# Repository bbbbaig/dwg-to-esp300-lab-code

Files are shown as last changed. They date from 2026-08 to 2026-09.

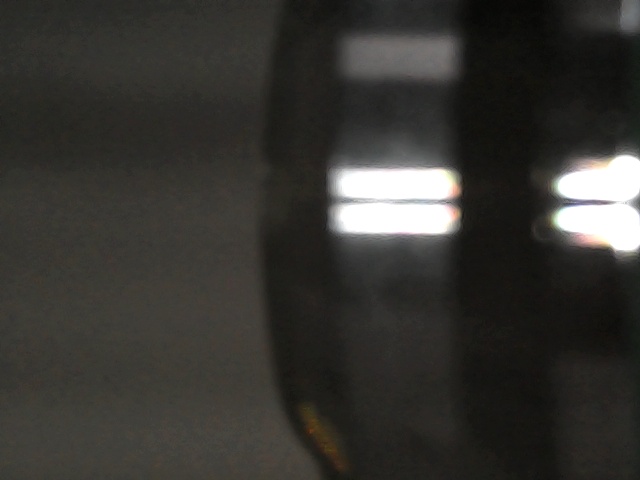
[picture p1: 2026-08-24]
camera_snapshot.jpg

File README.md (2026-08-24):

# DWG/DXF to ESP300 laser path

This project turns CAD geometry into an ESP300 stage-control Python script.
It follows the style of `ESP300_Controller.ipynb`: serial commands such as
`1PA...`, `2PA...`, `1VA...`, and `2VA...` are generated for the X/Y stage.

## Generate code from the sample DWG

The generated stage coordinates are always in millimeters. For the sample DWG,
the longest side is calibrated to 25 mm, which also makes the circular holes
about 2 mm in diameter.

```powershell
py dwg_to_esp300.py `
  "C:\Users\QCQN\Downloads\laser_shield\adjust25design.dwg" `
  --output adjust25design_esp300.py `
  --preview adjust25design_preview.svg `
  --fit-longest-mm 25 `
  --origin-x 0 `
  --origin-y 0 `
  --feed-rate 0.4 `
  --travel-rate 1.0 `
  --passes 1 `
  --ipynb
```

Generated files:

- `adjust25design_esp300.py`: executable ESP300 motion script
- `adjust25design_esp300.ipynb`: Jupyter notebook version when `--ipynb` is used
- `adjust25design_preview.svg`: path preview in machine millimeters
- `adjust25design.converted.dxf`: intermediate DXF when the input is DWG

Use `--notebook-output path\to\job.ipynb` if you want to choose the notebook
path explicitly.

## Run the generated machine script

Open and inspect the generated script first. The generated file now follows the
notebook style: `send()`, `move_abs()`, `move_rel()`, and `set_velocity()` are
top-level functions. Repeated cuts are stored as `PASSES = 5` when all selected
paths share the same count, or as per-path `passes` when they differ. The laser
hooks are intentionally no-ops unless you fill in laser trigger commands.
Default live speeds follow the field notebooks conservatively: `0.4 mm/s` for
cutting, `1.0 mm/s` for travel, and `0.3 mm/s` for Z motion.

```powershell
py adjust25design_esp300.py --dry-run
py adjust25design_esp300.py --live --port COM5
py adjust25design_esp300.py --live --port COM5 --passes 2
```

In Jupyter, open the generated `.ipynb`, run the setup cells, inspect
`METADATA`, and only set `LIVE_RUN = True` after checking the preview, COM port,
pass count, speed, and laser trigger commands.

## Visualize the generated movement

```powershell
py visualizer_server.py --host 127.0.0.1 --port 8765
```

Then open:

```text
http://127.0.0.1:8765
```

The visualizer reads the generated ESP300 scripts and animates the exact move
sequence. The full drawing view shows the 25.000 mm side; the outline view uses
only the `외형선(ISO)` layer.

The browser interface can now trace a new DWG/DXF directly:

- Choose a `.dwg` or `.dxf` file and press `Trace File`, or paste a local
  drawing path and press `Trace Path`.
- Use `직접 조합` to build paths without CAD. `빈 작업` starts an empty mm
  workspace, then add `직선`, `사각형`, or a fixed 2 mm `원`.
- `긴 변(mm)` sets the real-world size of the longest side. Use `25` for the
  current sample.
- Coordinates are generated in mm, and the circular-hole check is fixed at
  2 mm so it cannot be changed accidentally.
- Select paths from the canvas or the path list.
- Set pass counts per path, or use the global pass box and `Apply`.
- Keep `Optimize` enabled to reorder selected paths and repeated passes to
  reduce laser-off travel.
- Press `코드 다운로드` to write the selected plan under `generated/` and
  download the generated ESP300 Python file in the browser.

By default, generated path order is optimized to reduce laser-off travel moves.
Use `--no-optimize` only when you need to preserve the original CAD entity order.
By default, `--trace-mode design` excludes obvious watermark/support geometry
such as `layer 0` evaluation text and full-page diagonal strokes. Use
`--trace-mode all` only when you intentionally want every CAD entity.

## Notes

- DWG input is converted to DXF automatically with ODA File Converter when it is
  installed. If ODA is not found, the script tries `aspose-cad`.
- DXF input is parsed directly with `ezdxf`.
- The converter supports common curve geometry through `ezdxf.path.make_path`,
  including lines, polylines, arcs, circles, ellipses, and splines when `ezdxf`
  can flatten them.
- `--include-layer` and `--exclude-layer` accept shell-style wildcards.

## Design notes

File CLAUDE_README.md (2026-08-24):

# DWG to ESP300 Code Context

This repository/package is a local tool for converting DWG/DXF CAD geometry into
ESP300 stage-control Python code for laser engraving on a small glass sample.

The key physical assumption is that the laser beam is fixed and the glass/sample
stage moves in X, Y, and Z. During laser-off travel moves, the glass stage is
defocused in Z so the laser is not focused on the sample. During cutting moves,
the stage returns to the focus Z and the X/Y stage moves along the drawing path.
Default live speeds are set to conservative field-code values: cutting
`0.4 mm/s`, travel `1.0 mm/s`, Z motion `0.3 mm/s`, and serial command settle
`0.05 s`.

## Main Files

| File | Role |
| --- | --- |
| `dwg_to_esp300.py` | Command-line converter and ESP300 script generator. |
| `visualizer_server.py` | Local HTTP server/API for trace, plan, export, and download. |
| `visualizer/index.html` | Browser UI shell. |
| `visualizer/styles.css` | Browser UI styling. |
| `visualizer/app.js` | Frontend state, 2D canvas preview, and Three.js 3D visualization. |
| `visualizer/vendor/three.module.js` | Local Three.js dependency for the 3D view. |
| `adjust25design_2passes_esp300.py` | Example generated ESP300 script using two passes. |
| `adjust25design_2passes_esp300.ipynb` | Notebook form of the generated script. |
| `adjust25design_2passes_preview.svg` | Preview of the generated two-pass path. |
| `launch_dwg_to_esp300.ps1` | Windows launcher for the local app. |
| `requirements.txt` | Python dependencies. |
| `DWG_to_ESP300_Code_Overview_Lab_Report.pptx` | Plain lab-report slide deck explaining the code. |

## Conversion Pipeline

1. `dwg_to_esp300.py` accepts DWG or DXF input.
2. DWG input is converted to DXF when needed.
3. `ezdxf` extracts drawable geometry and flattens curves into point sequences.
4. The code filters likely annotation/helper geometry in design trace mode.
5. Geometry is scaled to millimeters and centered on the glass.
6. Scaling is capped so the path fits inside the centered 25 mm usable circle.
7. Optional path ordering optimization reduces non-cutting travel distance.
8. The generator writes an ESP300 Python script, optional notebook, and SVG preview.

## Motion Planning Logic

The server-side visualizer builds motion segments from selected paths:

- `z-defocus`: move glass Z away from focus before laser-off travel.
- `travel`: move X/Y with laser off and Z defocused.
- `z-focus`: return glass Z to focus before cutting.
- `cut`: move X/Y with laser on at focus Z.

The generated ESP300 script follows the same logic.

## Multi-Pass Logic

Each path can have its own pass count.

- Open paths alternate direction on repeated passes: forward, backward, forward,
  and so on.
- Closed paths repeat from an equivalent closed-loop start.
- The optimizer considers the expected endpoint after the requested pass count.

The optimizer is a heuristic, not a mathematical proof of the global shortest
route. It uses nearest-neighbor ordering and limited local search to reduce
travel.

## ESP300 Command Pattern

The generated script uses basic ESP300-style serial commands:

- `MO`: motor on
- `VA`: set axis velocity
- `PA`: absolute position move
- `TP`: read current position

X/Y synchronization is implemented by calculating a common move time for each
line segment:

```text
move_time = vector_distance / command_speed
vx = abs(dx) / move_time
vy = abs(dy) / move_time
```

Each axis receives its own velocity so both axes reach the endpoint together.

## Robustness Details

- `TP_READ_RETRIES = 5`
- Empty or unparseable `TP` replies are retried rather than treated as zero.
- Position wait loops tolerate intermittent TP failures.
- Extra settle time is applied after laser-off travel and Z focus/defocus moves.
- Z travel duration is computed from Z distance and configured Z speed.

## UI / Visualizer Details

The browser app provides:

- 2D drawing preview with the centered usable circle.
- 3D visualization showing the glass plate moving under a fixed laser tip.
- Path selection and per-path pass controls.
- Feed speed, travel speed, and Z speed controls.
- Export button that writes a generated ESP300 script into `generated/`.

The current UI uses side-by-side 2D and 3D panels on desktop. On small screens,
the panels stack vertically.

## Safety Notes

Before live use, confirm:

- The COM port and baudrate match the ESP300.
- Mechanical zero corresponds to the assumed glass center.
- The usable area matches the mounted sample and tape placement.
- The generated path stays inside the 25 mm circular usable area.
- Laser control is manual unless `LASER_ON_CMD` and `LASER_OFF_CMD` are filled
  with the correct device commands.

## Suggested Review Starting Points

1. Read `dwg_to_esp300.py` around `generate_esp300_script()`.
2. Read the generated `adjust25design_2passes_esp300.py` around `run_paths()`.
3. Read `visualizer_server.py` around `build_segments()`, `expand_passes()`, and
   `optimize_items()`.
4. Read `visualizer/app.js` around `updatePlan()`, `rebuildStage3d()`, and
   `updateStage3d()`.

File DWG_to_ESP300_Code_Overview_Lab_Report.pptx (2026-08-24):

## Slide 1

DWG to ESP300 코드 개요

연구실 보고서 형식

- 목적: CAD 도면을 ESP300 X/Y/Z 스테이지 구동 코드로 변환한다.
- 대상 장비: 25 mm x 25 mm 유리판이 움직이는 샘플 스테이지, 고정된 레이저 조사부.
- 주요 산출물: Python 실행 코드, Jupyter notebook, SVG preview, 브라우저 2D/3D visualizer.
- 본 슬라이드는 코드 구조와 실험 전 확인해야 할 동기화/초점 로직을 요약한다.

DWG to ESP300 code overview | 1/11

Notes: [Sources]
- README.md
- dwg_to_esp300.py
- visualizer_server.py
- visualizer/app.js

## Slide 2

실험 장치 전제를 코드에 고정했다

- 유리판 크기는 25 mm x 25 mm로 취급한다.
- 사용 가능 영역은 중앙 원형 영역이며, 기본 지름은 25 mm이다.
- 좌표 시작점은 유리판 중심, 즉 (12.5 mm, 12.5 mm)이다.
- 레이저는 고정되어 있고 실제 이동 대상은 유리판/스테이지이다.
- 기본 laser_on()/laser_off()는 출력문이며, TTL 제어 명령은 별도 입력 가능하다.

DWG to ESP300 code overview | 2/11

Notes: [Sources]
- dwg_to_esp300.py lines 1311-1368
- visualizer_server.py lines 135-145
- visualizer/app.js lines 622-650

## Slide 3

파일 구성은 변환, 서버, UI, 산출물로 나뉜다

Core files

- dwg_to_esp300.py: DWG/DXF geometry를 읽고 ESP300 Python script와 notebook을 생성한다.
- visualizer_server.py: local HTTP API로 trace, plan, export, download를 처리한다.
- visualizer/app.js: 2D preview와 3D 유리판 이동 시뮬레이션을 렌더링한다.

Run and outputs

- generated/: UI에서 export한 선택 경로별 ESP300 코드가 저장된다.
- launch_dwg_to_esp300.ps1: 바탕화면 바로가기에서 서버와 UI를 열기 위한 launcher이다.

DWG to ESP300 code overview | 3/11

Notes: [Sources]
- README.md
- REVIEW_PACKAGE_README.txt
- visualizer_server.py lines 739-895

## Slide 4

DWG/DXF 변환 파이프라인

- 1. DWG 입력은 DXF로 변환하거나, DXF 입력은 그대로 사용한다.
- 2. ezdxf로 LINE, POLYLINE, ARC, SPLINE 등 geometry를 점열로 flatten한다.
- 3. design trace mode에서는 주석/전역 보조선으로 보이는 path를 걸러낸다.
- 4. 단위는 mm 기준으로 변환하고, 도면을 유리판 중심에 맞춘다.
- 5. 최종 scale은 중앙 사용 가능 원 안에 들어가도록 한 번 더 제한한다.

DWG to ESP300 code overview | 4/11

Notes: [Sources]
- dwg_to_esp300.py lines 205-318
- dwg_to_esp300.py lines 324-406
- dwg_to_esp300.py lines 1317-1336

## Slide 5

경로 순서는 이동 거리 감소를 목표로 최적화한다

- 초기 순서는 현재 위치에서 가장 가까운 path를 고르는 greedy 방식이다.
- 열린 path는 시작점과 끝점 중 현재 위치에 가까운 방향으로 뒤집을 수 있다.
- 닫힌 path는 현재 위치와 가장 가까운 점을 시작점으로 회전한다.
- 이후 제한적인 local search로 순서를 개선한다.
- 따라서 전역 최단 경로 보장은 아니지만, 실험용 travel 감소 heuristic으로 동작한다.

DWG to ESP300 code overview | 5/11

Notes: [Sources]
- dwg_to_esp300.py lines 421-550
- visualizer_server.py lines 407-473

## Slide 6

passes가 2 이상일 때 이동 끝점을 고려한다

- 각 path의 pass count는 UI 또는 실행 인자로 지정된다.
- 열린 path는 pass마다 forward/backward를 번갈아 사용해 불필요한 되돌아가기를 줄인다.
- 닫힌 path는 같은 폐곡선 방향을 반복해도 끝점이 시작점과 같으므로 안정적이다.
- visualizer_server.py는 pass 이후 예상 endpoint를 계산해 다음 path 순서 최적화에 반영한다.
- 생성된 script도 같은 alternating-pass 규칙으로 실제 move를 실행한다.

DWG to ESP300 code overview | 6/11

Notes: [Sources]
- visualizer_server.py lines 368-418
- dwg_to_esp300.py lines 851-856
- dwg_to_esp300.py lines 979-996

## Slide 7

ESP300 명령은 축별 absolute move와 position wait로 구성된다

- 축 번호는 X=1, Y=2, Z=3으로 정의된다.
- 기본 명령 패턴은 MO, VA, PA, TP이다.
- move_abs()는 PA 명령, set_velocity()는 VA 명령을 보낸다.
- get_position()은 TP 응답을 읽고 빈 응답 또는 파싱 실패 시 5회 재시도한다.
- wait_xy_position()과 wait_axis_position()은 목표 좌표 도달 여부를 position tolerance로 확인한다.

DWG to ESP300 code overview | 7/11

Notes: [Sources]
- dwg_to_esp300.py lines 610-632
- dwg_to_esp300.py lines 733-818

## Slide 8

X/Y 동기화는 같은 도착 시간을 만들도록 계산한다

- 직선 segment의 전체 이동 시간은 vector distance / command speed로 계산한다.
- X축 속도는 abs(dx) / move_time, Y축 속도는 abs(dy) / move_time로 설정한다.
- 두 축의 PA 명령은 거의 연속으로 전송되어 같은 시간에 목표점에 도달하도록 한다.
- position wait mode에서는 TP 기반으로 실제 도달을 확인한다.
- Y축 관련 짧은 멈춤/드리프트 완화를 위해 travel 이후 추가 settle time을 둔다.

DWG to ESP300 code overview | 8/11

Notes: [Sources]
- dwg_to_esp300.py lines 925-959
- dwg_to_esp300.py lines 624-627

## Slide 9

Laser-off travel에서는 유리판 Z를 defocus한다

- 다음 cut 시작점까지 XY travel이 필요할 때만 laser off와 Z defocus를 수행한다.
- 기본 defocus는 focus_z에서 1 mm 이동하며, 이동 시간은 Z speed로 계산된다.
- Z 이동 후에는 position wait 또는 sleep wait를 적용하고 settle time을 둔다.
- 연속된 cut 구간 또는 같은 위치에서 다시 자르는 경우에는 굳이 Z를 바꾸지 않는다.
- 마지막 종료 단계에서도 laser off 후 defocus 위치로 이동해 안전 상태로 마무리한다.

DWG to ESP300 code overview | 9/11

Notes: [Sources]
- visualizer_server.py lines 231-327
- dwg_to_esp300.py lines 859-923
- dwg_to_esp300.py lines 963-976
- dwg_to_esp300.py lines 1021-1034

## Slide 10

Visualizer는 계획과 실제 코드 생성을 연결한다

- 2D panel은 도면 경로, 중앙 사용 가능 원, 진행된 cut/travel segment를 표시한다.
- 3D panel은 고정 레이저 아래에서 유리판과 도면이 X/Y/Z로 움직이는 모습을 보여준다.
- 사용자는 path 선택, pass count, feed/travel/Z speed, optimize 여부를 조정할 수 있다.
- /api/plan은 선택된 경로를 motion segment로 만들고, /api/export는 ESP300 script를 생성한다.
- 현재 UI는 2D와 3D를 좌우 배치하여 공간 활용과 가시성을 개선했다.

DWG to ESP300 code overview | 10/11

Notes: [Sources]
- visualizer/app.js lines 109-120
- visualizer/app.js lines 321-370
- visualizer/app.js lines 488-930
- visualizer_server.py lines 778-895

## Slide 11

검증 상태와 실제 실행 전 확인 사항

- Python compile check와 JavaScript parser check를 통과했다.
- 생성된 2-pass path는 25 mm 중앙 원 안에 margin 0.05 mm 조건으로 배치된다.
- TP read retry, empty TP handling, travel/Z settle time 보강이 반영되어 있다.
- Live run 전에는 dry-run 출력, visualizer path, mechanical zero, sample mounting을 확인해야 한다.
- 남은 한계: 최적화는 heuristic이며, 실제 레이저 TTL 제어는 장비 연결 방식에 맞춰 별도 검증이 필요하다.

DWG to ESP300 code overview | 11/11

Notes: [Sources]
- REVIEW_PACKAGE_README.txt
- dwg_to_esp300.py
- visualizer_server.py
- visualizer/app.js

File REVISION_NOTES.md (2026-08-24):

# DWG to ESP300 Lab Code Package — 개정 내역

개정일: 2026-08-17
대상 패키지: DWG_to_ESP300_Lab_Code_Package_2026-08-16
변경 파일: `visualizer_server.py`, `dwg_to_esp300.py`, `visualizer/index.html`, `visualizer/app.js`, `visualizer/styles.css`

## 1. 개요

기존 패키지는 DWG/DXF 도면을 ESP300 스테이지 제어 코드로 변환하고 미리보기하는 기능까지 제공하였다. 본 개정에서는 브라우저 인터페이스에서 ESP300을 직접 수동 조작(조그, joystick jog)할 수 있는 기능을 추가하고, 시리얼 통신 안정성 및 다중 패스 가공 관련 사항을 보완하였다.

## 2. 신규 기능

### 2.1 수동 조그(Joystick) 제어 패널

시각화 인터페이스(`visualizer/`)에 실기계 수동 이동 제어 패널을 신설하였다. 백엔드는 `visualizer_server.py`의 `JogController` 클래스가 담당하며, ESP300과의 시리얼 통신은 기존 생성 스크립트와 동일한 명령 체계(VA, PA, MO, MF, TP, AB)를 사용한다.

| 기능 | 설명 |
|---|---|
| 연결(Connect) | COM 포트, 통신 속도, X/Y 및 Z 소프트 리밋 범위 지정. Dry run(가상 실행) 모드 기본 적용 |
| 축별 조그 이동 | X, Y, Z 축 개별 이동. 이동 단위 0.001mm(1μm)~5mm 중 선택 가능. 버튼 길게 누름으로 연속 이동, 포인터 해제 시 즉시 정지 |
| 키보드 단축키 | 방향키(X/Y), Page Up/Down(Z), Space(비상정지) |
| 비상정지(E-STOP) | 전축 정지 및 모터 비활성화 명령 전송, 진행 중인 자동 실행도 함께 중단. 재사용 시 재연결 필요 |
| 원점 이동(Home) | 소프트웨어 기준 원점(0,0,0)으로 절대 이동 |
| 로컬 원점 설정 | 현재 위치를 임의 좌표(통상 도면 중심)로 라벨링. **ESP300 자체의 절대 좌표계는 변경하지 않으며, 물리적 이동도 발생하지 않는다.** 소프트웨어 계층에서만 좌표 오프셋을 관리한다 |
| 좌표 직접 이동(Go to) | X/Y/Z 좌표 직접 입력 후 절대 이동, 소프트 리밋 적용 |
| 계획 경로 실행(Run on machine) | 화면에 표시된 가공 계획(경로 계획)을 실기계가 순차 실행. 실행 진행 상황에 따라 화면 재생 위치가 동기화된다 |
| 실시간 위치 표시 | 조그 조작 또는 외부 조작으로 발생한 실제 스테이지 이동이 3차원 미리보기 및 좌표 표시에 실시간 반영된다 |

안전 관련 사항: X/Y 이동은 원형 작업영역 반경으로, Z 이동은 지정 범위로 제한된다. 단일 조그 이동 최대 거리는 5mm로 고정되어 있다. 원점 이동, 좌표 직접 이동 등 상대적으로 큰 이동을 수반하는 동작은 실행 전 확인 절차를 거친다.

### 2.2 다중 패스 가공 시 Z축 보정

동일 경로를 다중 패스(pass)로 반복 가공할 경우, 2패스마다 초점(focus) Z 위치를 디포커스 방향으로 1μm(0.001mm)씩 후퇴시키는 로직을 추가하였다. 이는 반복 가공에 따른 가공면 침하를 보정하기 위한 것이다. 경로가 전환되면 해당 보정값은 자동으로 초기화된다.

적용 범위: 생성되는 독립 실행 스크립트(`dwg_to_esp300.py`의 `generate_esp300_script` 출력) 및 시각화 인터페이스의 경로 계획·실기계 실행 기능(`visualizer_server.py`) 양쪽 모두.

### 2.3 도면 배치 회전(45도)

원형 작업영역(지름 25mm)에 도면을 맞춰 넣을 때, 도면을 자체 중심 기준 45도 회전한 뒤 배율을 계산하도록 변경하였다. 정사각형이 아닌 배치의 경우, 회전 적용 시 축 정렬 배치 대비 더 큰 배율로 작업영역에 수용할 수 있다. 기본값은 45도이며, 0으로 설정 시 비활성화된다.

적용 범위: CLI 옵션(`--rotate-deg`, `dwg_to_esp300.py`) 및 브라우저 인터페이스(툴바 "Rotate (deg)" 입력란).

## 3. 결함 수정

### 3.1 시리얼 응답 처리 오류

위치 조회(TP) 명령에 대한 응답을 수신 완료로 판단하는 기준이 불명확하여, 응답이 통신 구간에서 분할 수신되는 경우 이전 응답의 잔여 바이트가 다음 응답에 혼입되는 결함이 있었다. 이로 인해 실제 위치값이 정상 범위를 크게 벗어난 값(예: 400mm 이상)으로 오표시되는 현상이 발생하였다.

조치: 응답 종결 문자(캐리지리턴/개행)를 확인한 후 응답 완료로 판단하도록 변경하였으며, 파싱된 값이 축 이동 범위를 초과하는 경우(250mm 초과) 해당 값을 폐기하고 재조회하도록 방어 로직을 추가하였다.

### 3.2 원점 이동 기능 오동작

`JogController` 클래스 내부에서 속성명과 메서드명이 중복되어(`home`) 원점 이동 기능 호출 시 오류가 발생하던 결함을 수정하였다.

### 3.3 인터페이스 레이아웃 오류

조그 패널 추가로 인해 우측 패널의 그리드 레이아웃 정의가 실제 구성요소 수와 불일치하여 하위 요소(도형 편집, 경로 목록)가 정상적으로 선택되지 않던 문제를 수정하였다.

## 4. 참고 및 제한사항

- **Python 버전 호환성**: `visualizer_server.py`는 `cgi` 모듈을 사용하며, 이는 Python 3.13부터 표준 라이브러리에서 제거되었다. Python 3.12 이하 환경에서 실행할 것을 권장한다.
- **전원 관리**: 실행 환경(PC)이 절전 모드로 전환되는 경우 USB 시리얼 연결이 끊기거나 포트 번호가 변경될 수 있다. 조그 조작 또는 자동 실행 중에는 운영체제 절전 설정을 비활성화할 것을 권장한다.
- DWG 파일 변환을 위하여 `aspose-cad` 패키지를 추가 설치하였다(ODA File Converter 미설치 환경 대응).

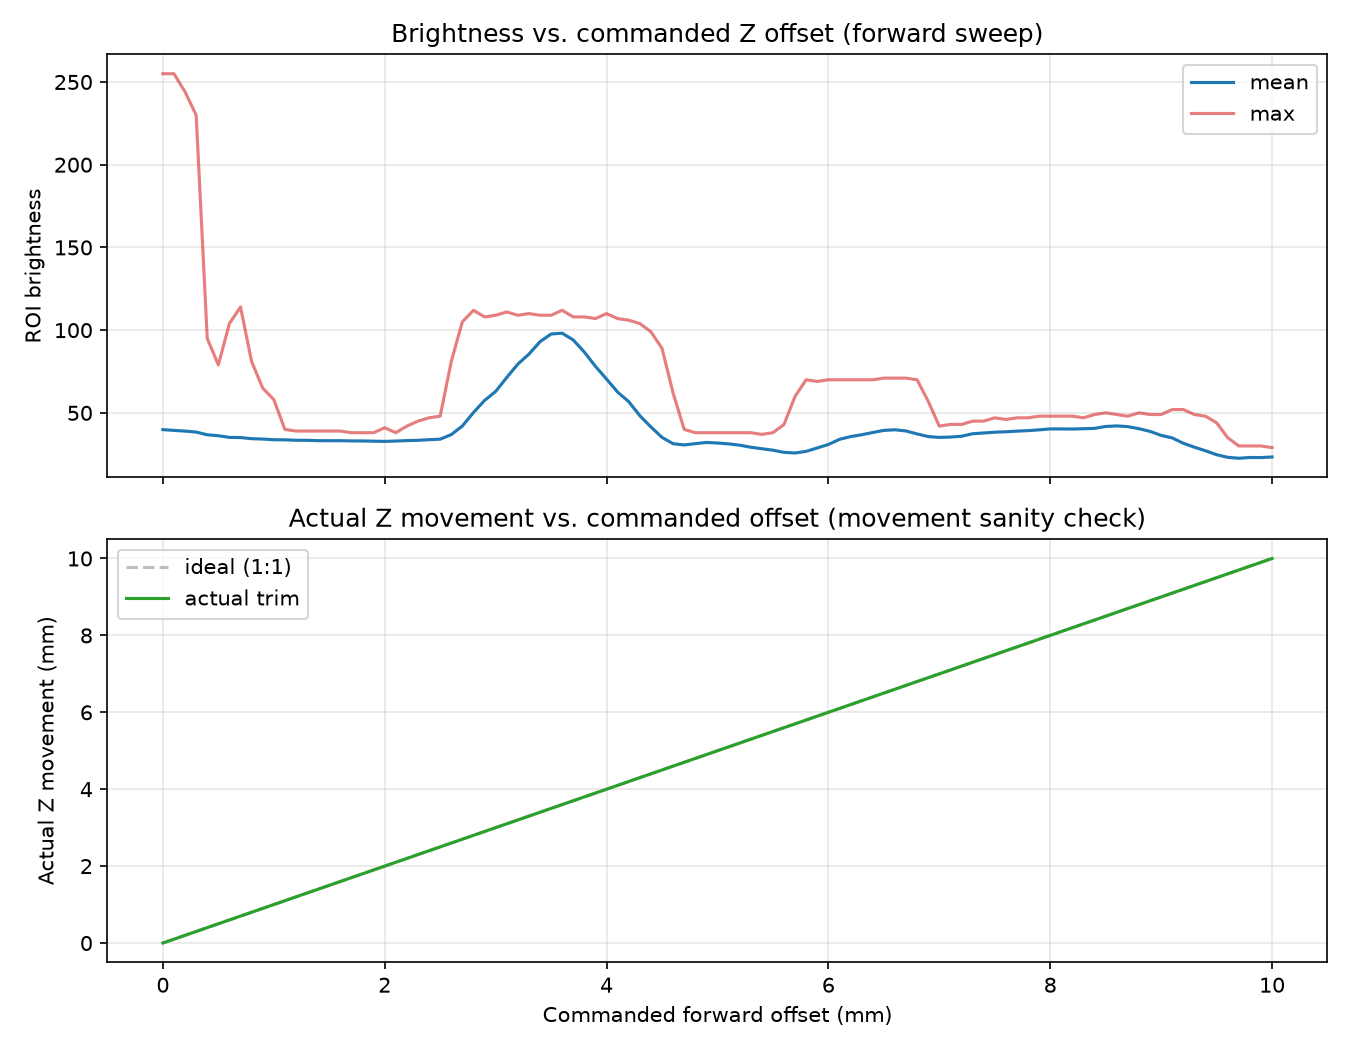
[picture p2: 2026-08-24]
zaxis_diagnostic.png

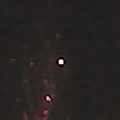
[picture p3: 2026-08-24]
camera_hotspot_check.jpg

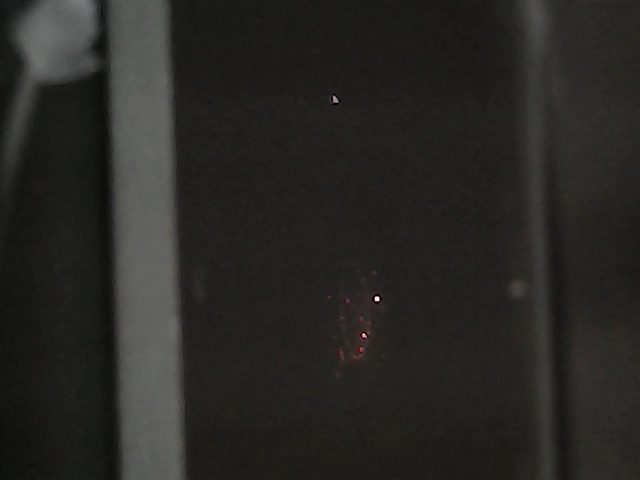
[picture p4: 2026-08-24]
camera_snapshot3.jpg

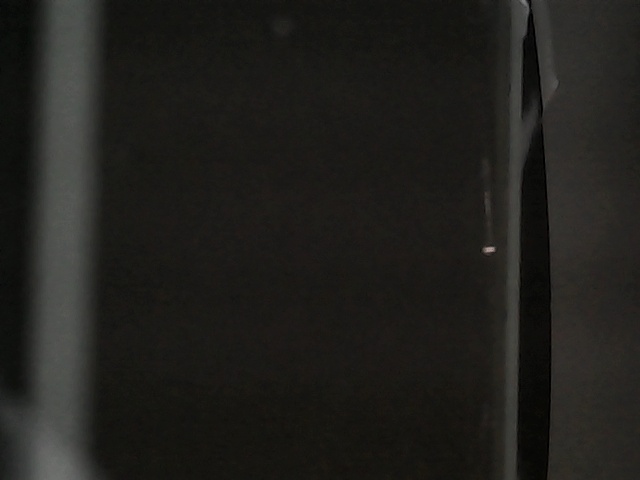
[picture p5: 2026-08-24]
camera_snapshot2.jpg

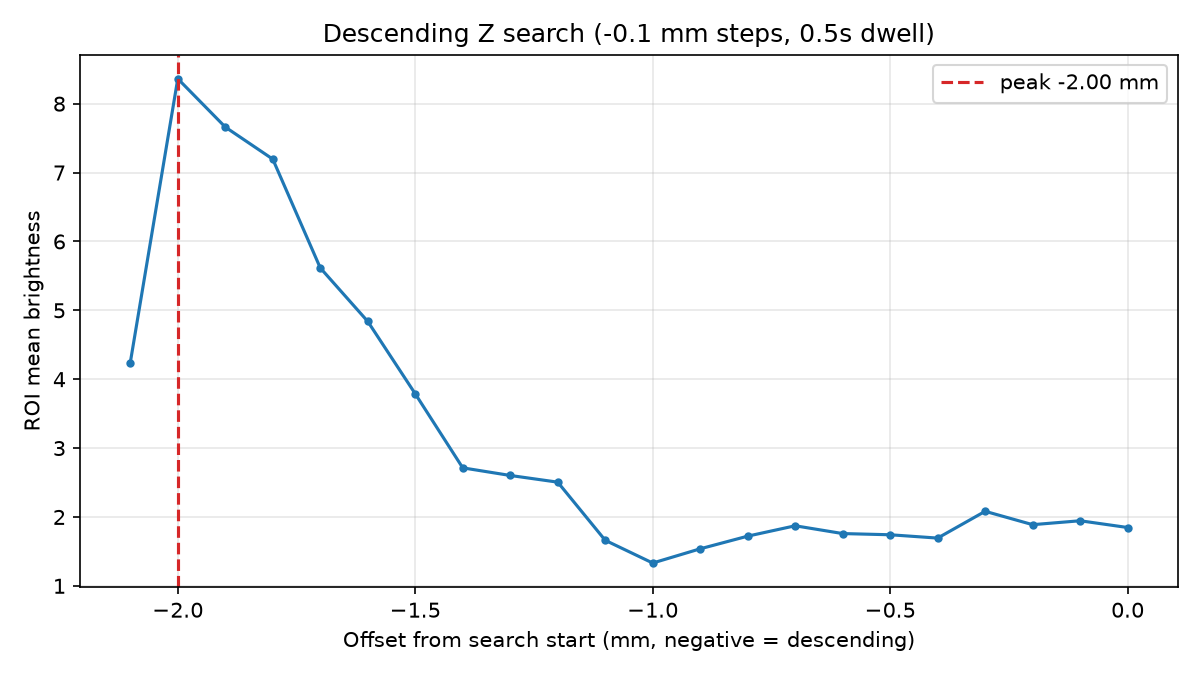
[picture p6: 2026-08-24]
descending_search.png

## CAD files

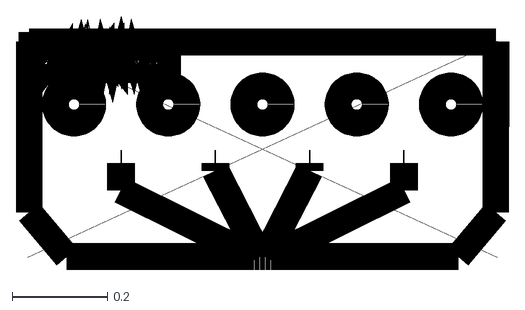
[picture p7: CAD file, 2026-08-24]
generated/adjust25design_ee601a7d4dee_esp300.converted.dxf
1.03 x 0.532

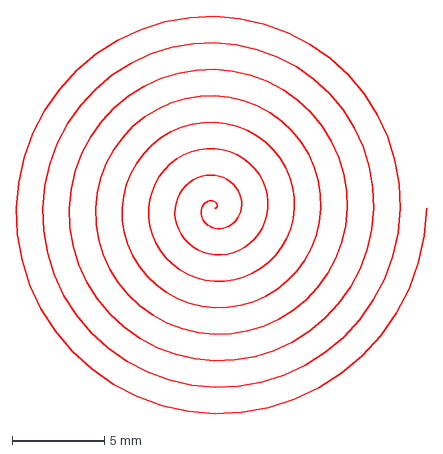
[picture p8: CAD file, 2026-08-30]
spiral_survey.dxf
22.3 x 21.6 mm

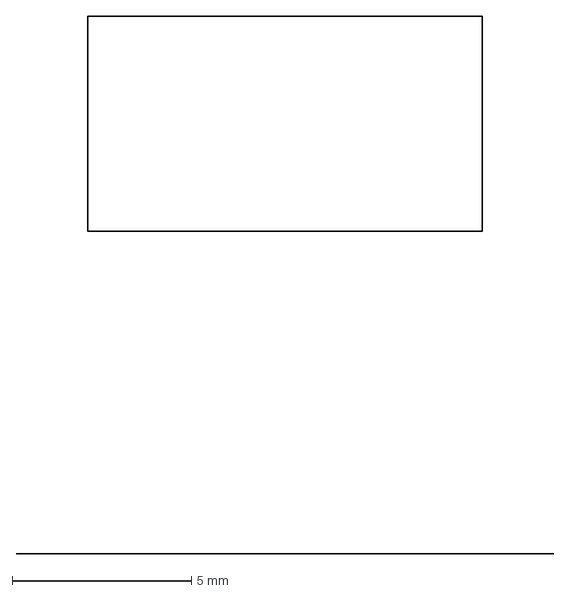
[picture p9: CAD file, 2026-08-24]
focus_test_line_rect.dxf
15.0 x 15.0 mm

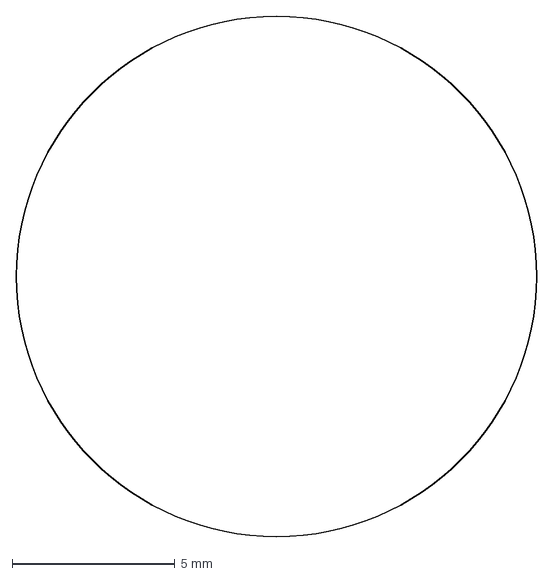
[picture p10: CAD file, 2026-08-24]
focus_test_circle.dxf
16.0 x 16.0 mm

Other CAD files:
focus_test_line.dxf
focus_test_2mm_line_x.dxf

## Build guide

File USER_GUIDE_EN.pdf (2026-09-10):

### DWG to ESP300

USER GUIDE

# From one drawing to a moving laser

DWG to ESP300 turns a drawing into laser stage motion,

### focuses the beam automatically with a camera, and lets you

watch the real machine as it runs — all from one screen. This guide takes you through every step, start to finish.

DWG to ESP300 · User Guide | 2026-09-10

DWG to ESP300 | User Guide

GETTING STARTED

# What does this app do?

It loads a drawing, lets you preview it, and runs the real machine — all in one window.

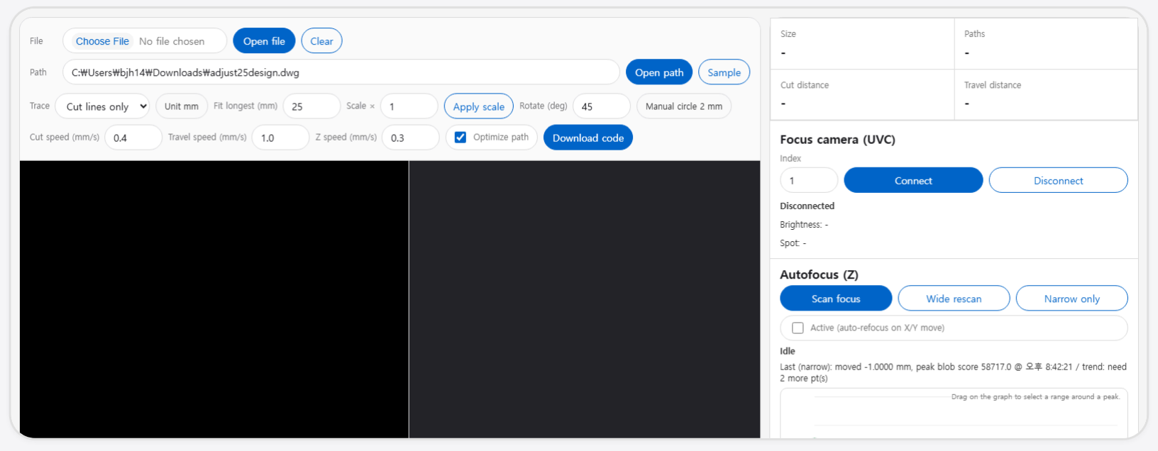
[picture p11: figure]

### 1 Load a drawing

Start by opening a drawing file (DWG or DXF) you already have.

### 2 Preview it on screen

See exactly how it will move, in both 2D and 3D, before anything happens.

### 3 Let the camera focus it

The connected camera finds the sharpest position on its own.

### 4 Run it on the real machine

Once you're happy with the preview, run the same plan for real.

DWG to ESP300 User Guide | 2

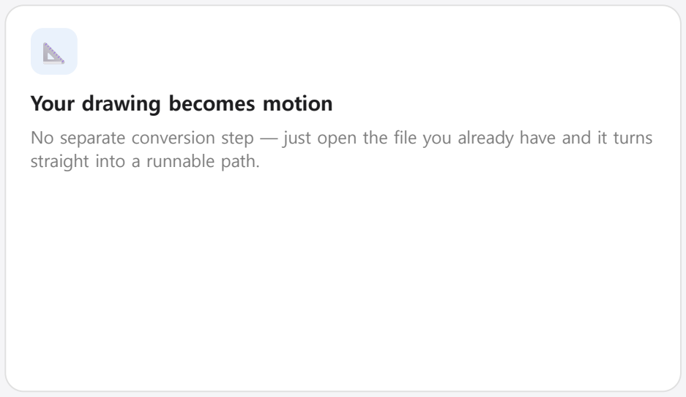
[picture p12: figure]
Your drawing becomes motion; straight into a runnable path.
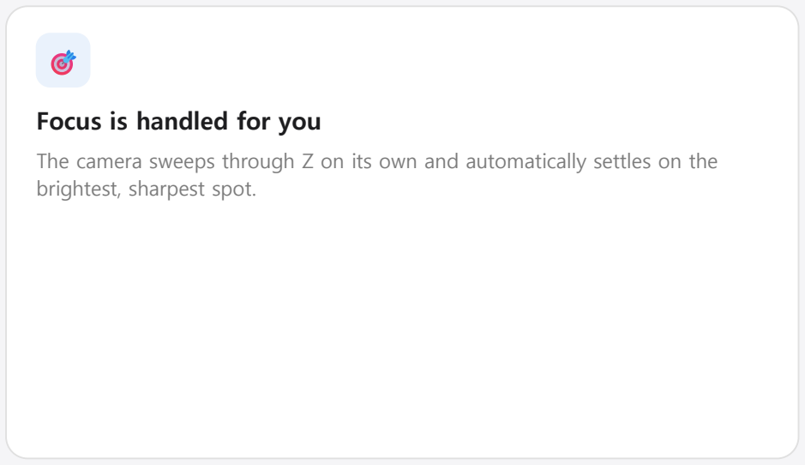
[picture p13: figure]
Focus is handled for you; brightest, sharpest spot.

GETTING STARTED

# Key features

Four things that make this app worth using.

No separate conversion step — just open the file you already have and it turns

The camera sweeps through Z on its own and automatically settles on the

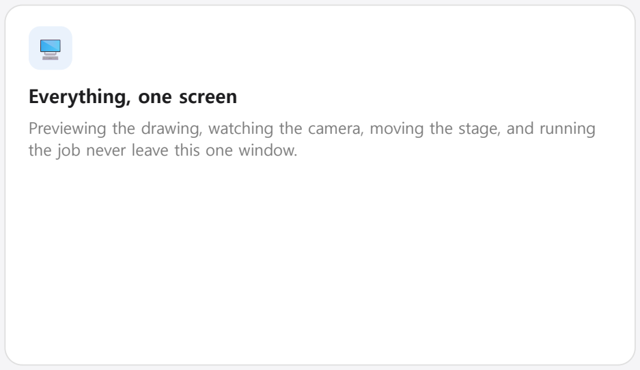
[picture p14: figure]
Everything, one screen; the job never leave this one window.

Previewing the drawing, watching the camera, moving the stage, and running

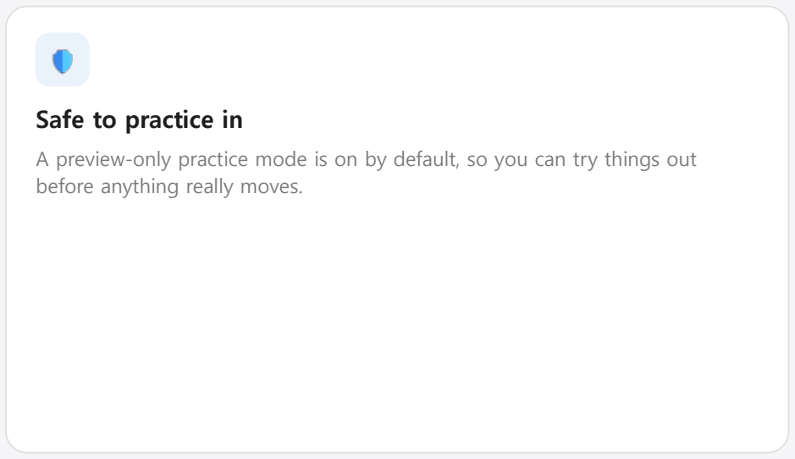
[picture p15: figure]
Safe to practice in; before anything really moves.

A preview-only practice mode is on by default, so you can try things out

FIRST LAUNCH · STEP 01

# Before you start

One icon on the desktop is all it takes to launch the app.

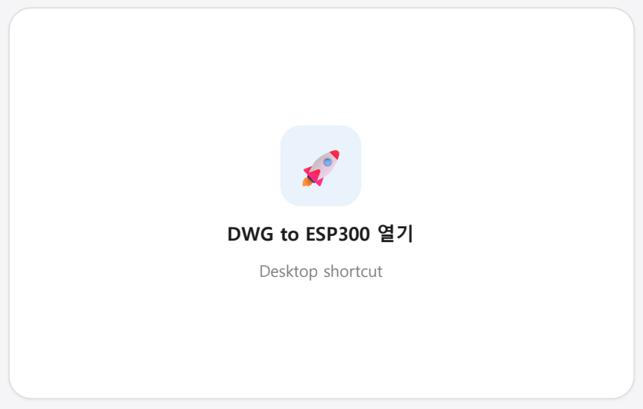
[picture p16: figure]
DWG to ESP300 열기; Desktop shortcut

### 1 Double-click "DWG to ESP300 열기" on the desktop

The app starts, and a browser window opens on its own a moment later.

### 2 Give it a few seconds

The very first launch can take a little longer than usual.

### 3 Already running? No need to relaunch

Clicking the icon again just brings you back to the window that's already open.

Good to know. If the computer goes to sleep, the connection to the machine can drop. Turn off sleep mode while you're working.

MAIN SCREEN · STEP 02

# The main screen at a glance

The screen splits into two halves: your workspace on the left, the tool panel on the

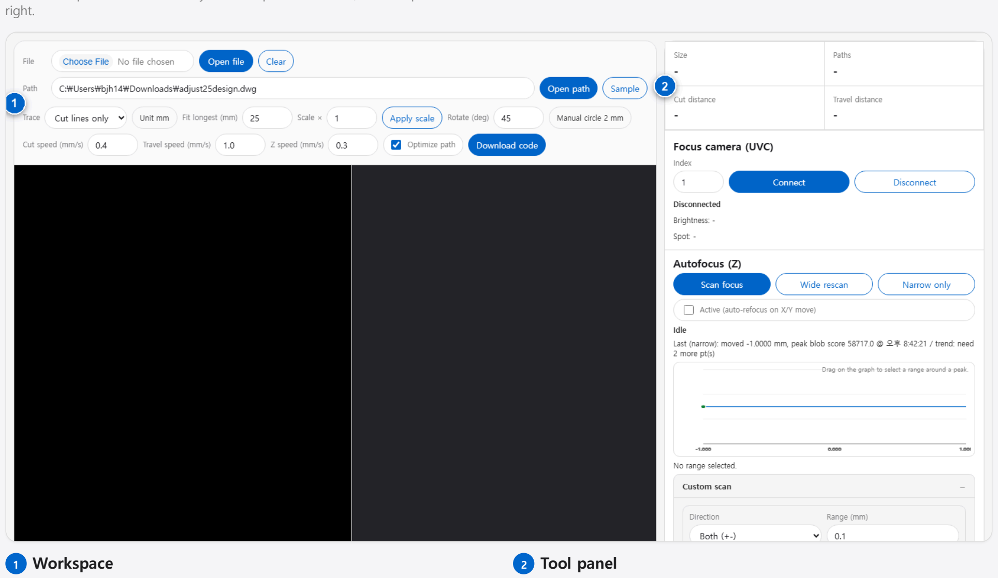
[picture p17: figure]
right.; 1 Workspace; 2 Tool panel

Where you open a drawing, check it, and play it back.

The camera view, focus controls, and machine controls all live here.

# Load a drawing

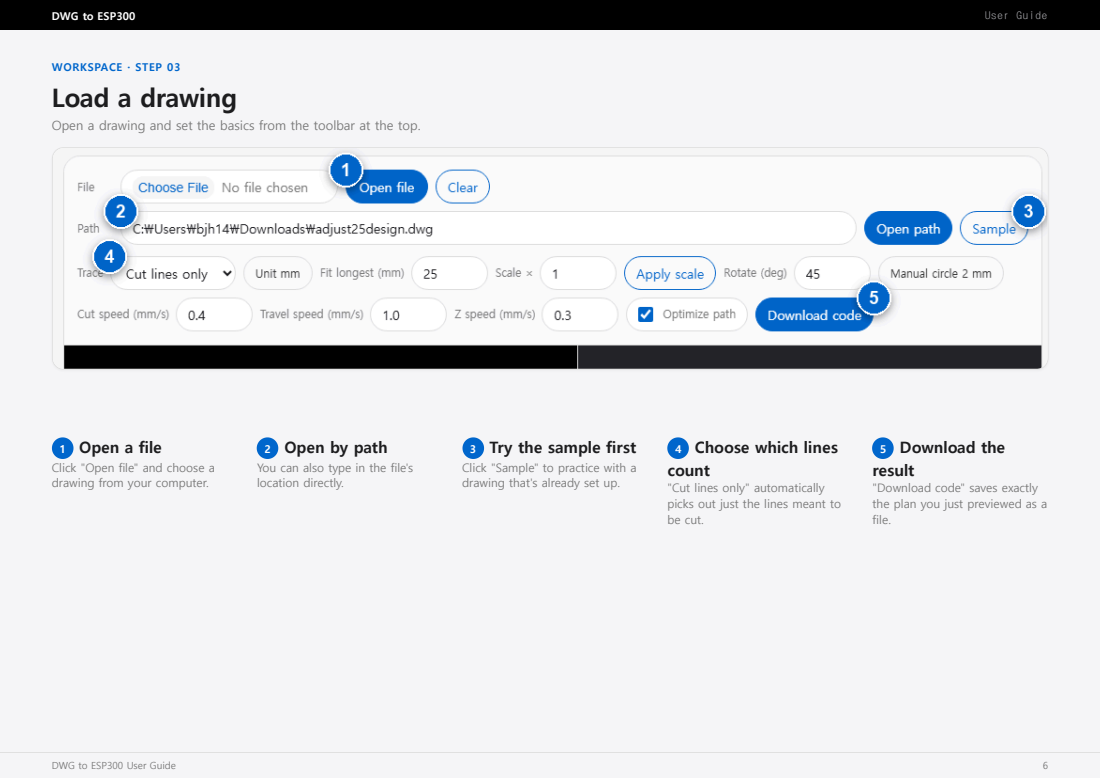
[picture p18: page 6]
WORKSPACE · STEP 03

Open a drawing and set the basics from the toolbar at the top.

1 Open a file
Click "Open file" and choose a
drawing from your computer.

2 Open by path
You can also type in the file's
location directly.

3 Try the sample first
Click "Sample" to practice with a
drawing that's already set up.

4 Choose which lines
count
"Cut lines only" automatically
picks out just the lines meant to
be cut.

5 Download the
result
"Download code" saves exactly
the plan you just previewed as a
file.

WORKSPACE · STEP 04

# Check it in the preview

Before anything runs for real, see how it will move right on screen.

### 1 Play the motion back

Press ▶ to play the path in real order. Drag the bar underneath to jump straight to any point.

The left side is a top-down 2D view; the right side looks like the real machine in 3D. Drag with your mouse on the 3D view to rotate it to any angle.

Good to know. The bar at the bottom shows the laser on/off state, the current height, and progress, all updating live.

# Watch the camera live

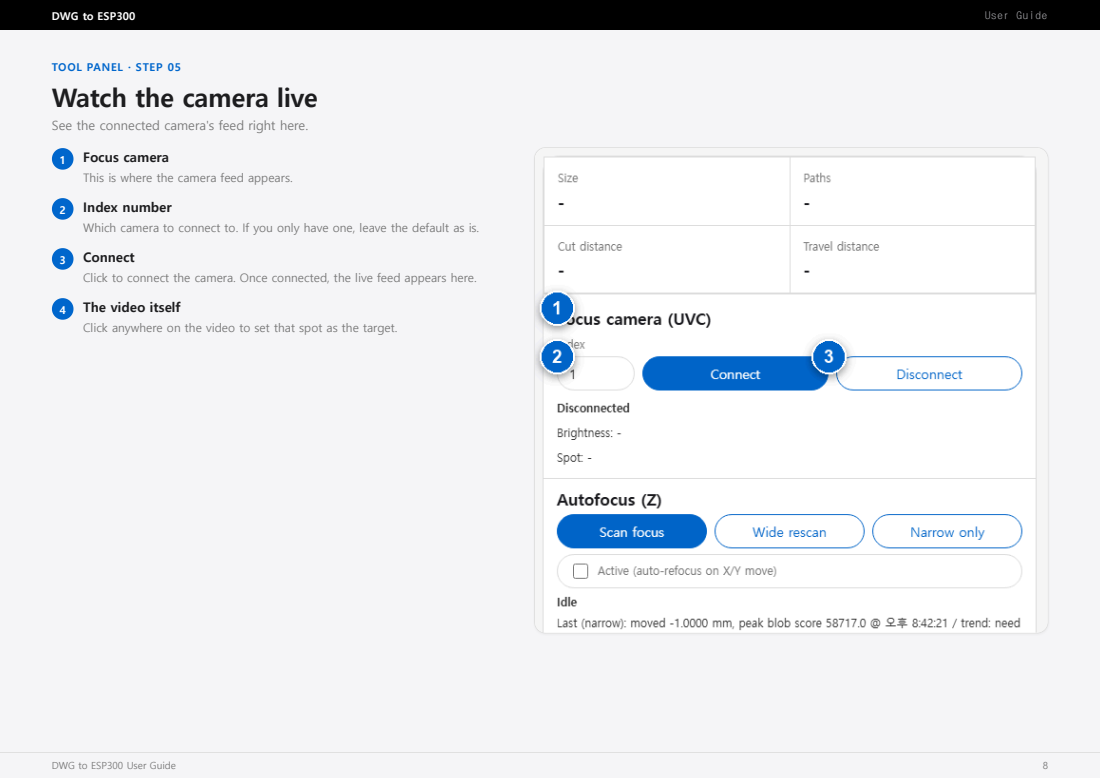
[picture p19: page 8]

TOOL PANEL · STEP 05

See the connected camera's feed right here.

1 Focus camera
This is where the camera feed appears.
2 Index number
Which camera to connect to. If you only have one, leave the default as is.
3 Connect
Click to connect the camera. Once connected, the live feed appears here.
4 The video itself
Click anywhere on the video to set that spot as the target.

TOOL PANEL · STEP 06

# Let it focus automatically

One click finds the sharpest height for you.

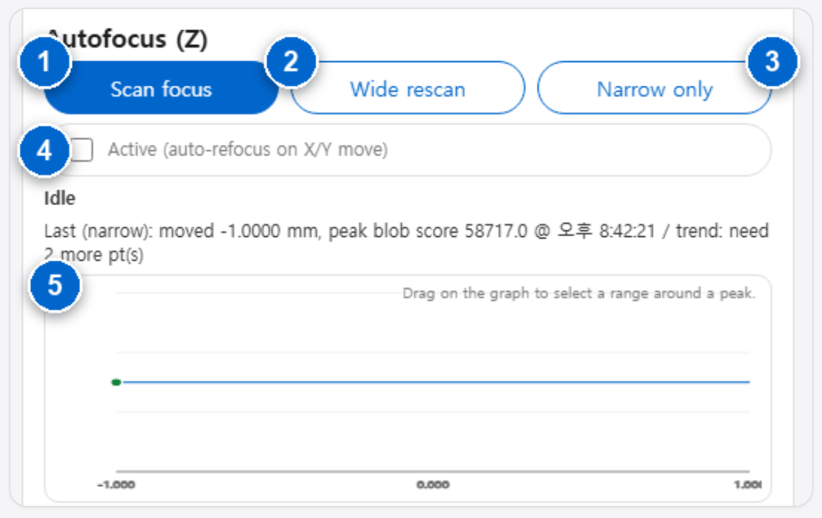
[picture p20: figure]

### 1 Scan focus

The standard way to focus. Use this right after connecting.

### 2 Wide rescan

Looks over a wider range. Use this if focus seems way off.

### 3 Narrow only

A quicker recheck over a small range.

### 4 Active

Turn this on and focus is automatically re-checked every time you move to a new spot.

### 5 The chart

Shows which height was brightest. Drag across it to re-check just that range.

# Fine-tune the focus further

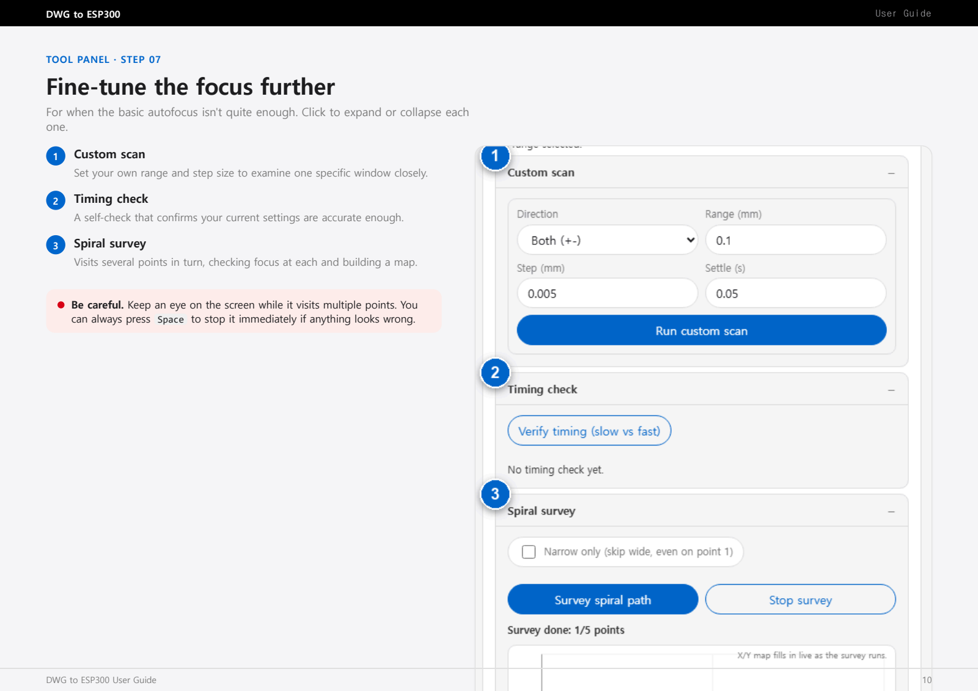
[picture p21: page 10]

TOOL PANEL · STEP 07

For when the basic autofocus isn't quite enough. Click to expand or collapse each one.

### 1 Custom scan

Set your own range and step size to examine one specific window closely.

### 2 Timing check

A self-check that confirms your current settings are accurate enough.

### 3 Spiral survey

Visits several points in turn, checking focus at each and building a map.

Be careful. Keep an eye on the screen while it visits multiple points. You can always press Space to stop it immediately if anything looks wrong.

TOOL PANEL · STEP 08

# Connect the machine

Before moving the real machine, you need to connect to it first.

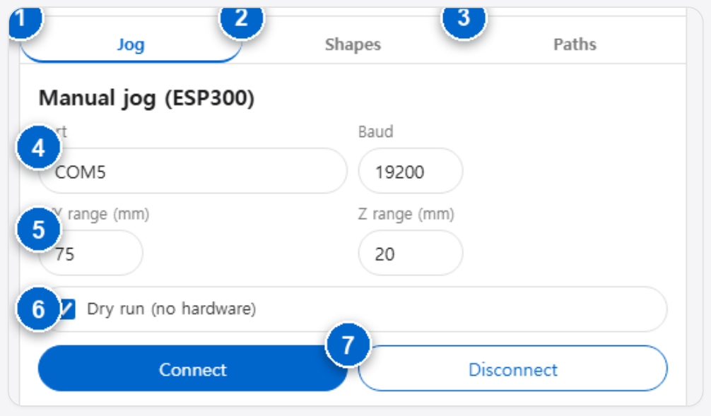
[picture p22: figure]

### 1 Jog tab

Where you drive the machine directly. Open by default.

### 2 Shapes tab

Draw your own shapes without a drawing file.

### 3 Paths tab

Manage each loaded path one by one.

### 4 Port

The communication port the machine is connected through. Leave the default unless you've been told otherwise.

### 5 Travel range

The farthest the machine is allowed to move. If it ever tries to go past this, it stops automatically for safety.

### 6 Dry run (practice mode)

While checked, nothing really moves — you only see it on screen. Uncheck it when you're ready for real motion.

### 7 Connect

Click to connect to the machine.

TOOL PANEL · STEP 09

# Move it by hand

Once connected, the arrow buttons let you drive the machine yourself.

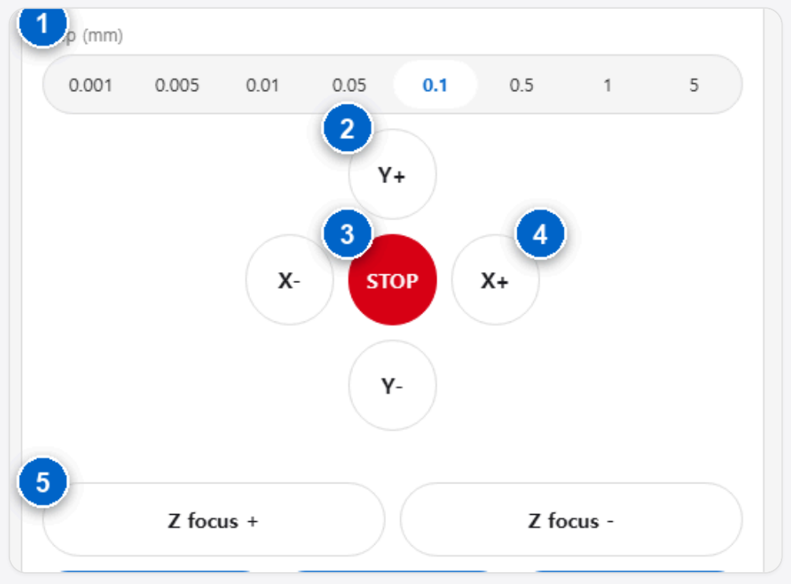
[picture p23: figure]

### 1 Distance per press

Choose how far one press moves. Smaller numbers mean smaller steps.

### 2 Direction buttons

Hold one down and it keeps moving that way. The arrow keys on your keyboard do the same thing.

### 3 Emergency stop

The red STOP button in the middle. It stops instantly, and you'll need to connect again before moving further. The Space key does the same thing.

### 4 Focus height

The Z focus buttons nudge the height (focus) up or down a little at a time.

Be careful. It's always safe to hit the emergency stop. It's built to stop instantly, no confirmation needed.

TOOL PANEL · STEP 10

# Set a home position, then run

Save the spots you use often, and run for real once you're ready.

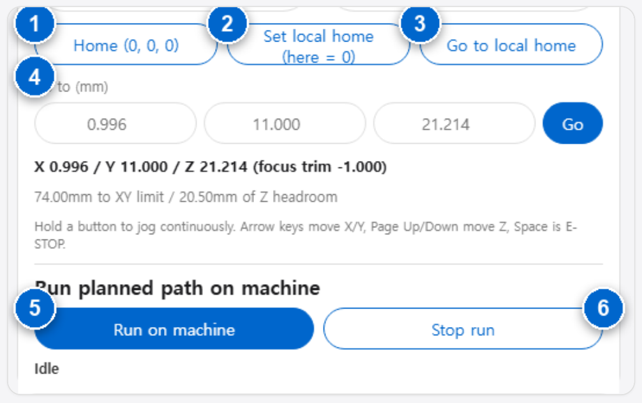
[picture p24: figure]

### 1 Home

Moves to the machine's original reference point (0,0,0). This can be a large move, so it asks you to confirm first.

### 2 Set local home

Saves the current spot as your own reference point. The real machine doesn't move.

### 3 Go to local home

Returns to the reference point you saved.

### 4 Go to coordinates

Type in the position you want (X/Y/Z) and press "Go".

### 5 Run on machine

Runs the plan you've been previewing on the real machine. Asks you to confirm before it starts.

### 6 Stop run

Stops a run that's already in progress.

# Draw shapes without a drawing

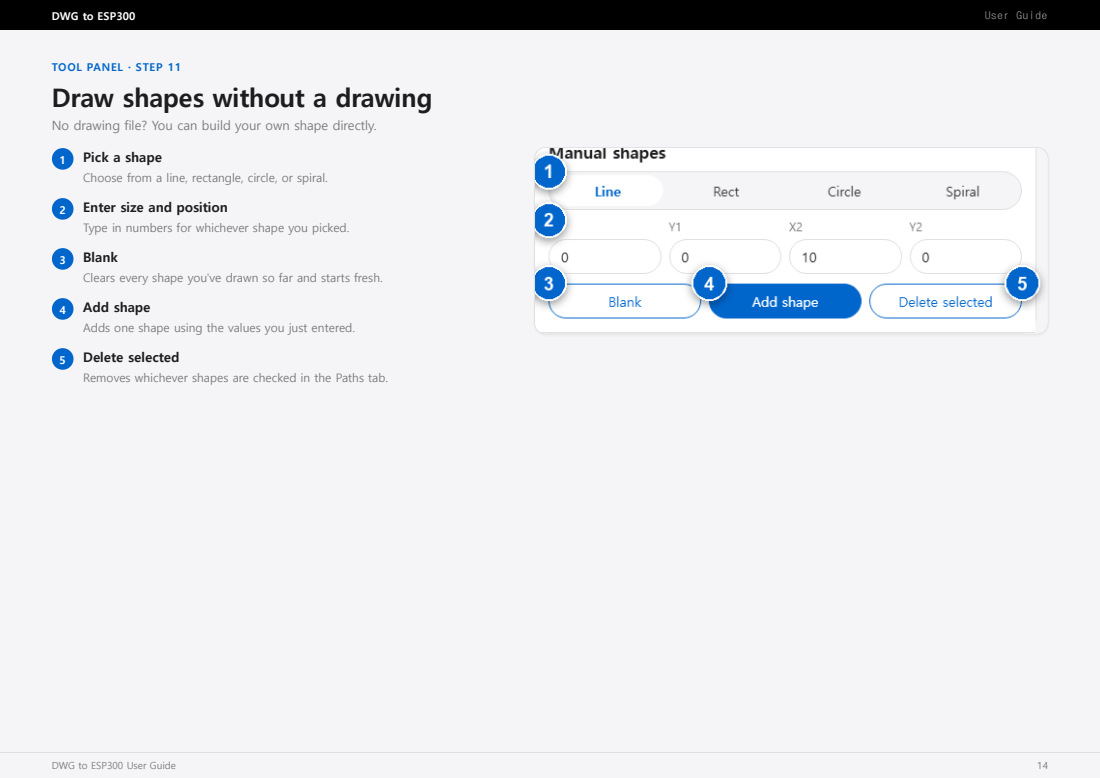
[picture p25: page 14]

TOOL PANEL · STEP 11

No drawing file? You can build your own shape directly.

1 Pick a shape
Choose from a line, rectangle, circle, or spiral.
2 Enter size and position
Type in numbers for whichever shape you picked.
3 Blank
Clears every shape you've drawn so far and starts fresh.
4 Add shape
Adds one shape using the values you just entered.
5 Delete selected
Removes whichever shapes are checked in the Paths tab.

# Choose and manage paths

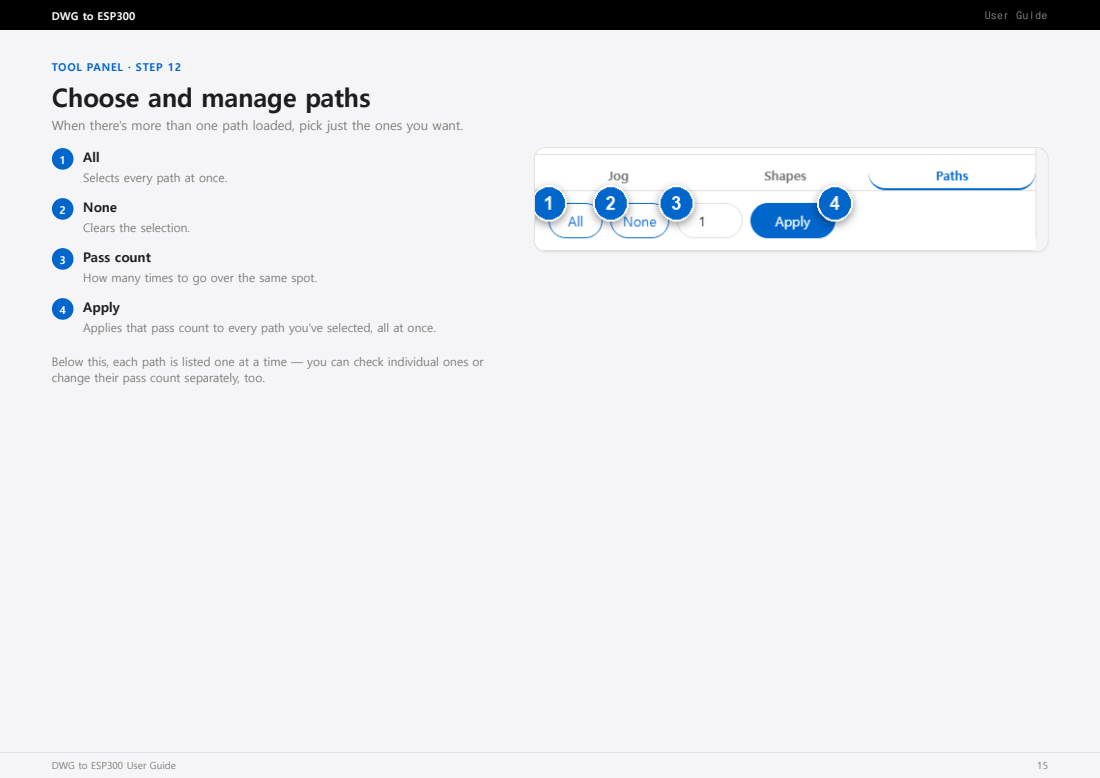
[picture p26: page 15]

TOOL PANEL · STEP 12

When there's more than one path loaded, pick just the ones you want.

1 All
Selects every path at once.
2 None
Clears the selection.
3 Pass count
How many times to go over the same spot.
4 Apply
Applies that pass count to every path you've selected, all at once.

Below this, each path is listed one at a time — you can check individual ones or
change their pass count separately, too.

SETTINGS · STEP 13

# A look at the settings

There's no separate "Settings" screen — you type numbers in right next to each
feature. Here's a quick reference for the ones you'll see most.
NAME | WHERE TO FIND IT | WHAT IT CONTROLS | DEFAULT
Cut speed | Load-a-drawing screen | How fast it moves while actually cutting | 0.4mm/s
Travel speed | Load-a-drawing screen | How fast it moves when not cutting | 1.0mm/s
Z speed | Load-a-drawing screen | How fast the focus height changes | 0.3mm/s
Travel range (X-Y) | Connect-the-machine screen | The farthest it can move side to side / front to back | 75mm
Travel range (Z) | Connect-the-machine screen | The farthest it can move up and down | 20mm
Distance per press | Move-it-by-hand screen | How far one button press moves it | 0.1mm

Good to know. The travel range values are there for safety. Unless you have a specific reason to change them, it's best to leave the defaults as they are.

# The whole thing in five steps

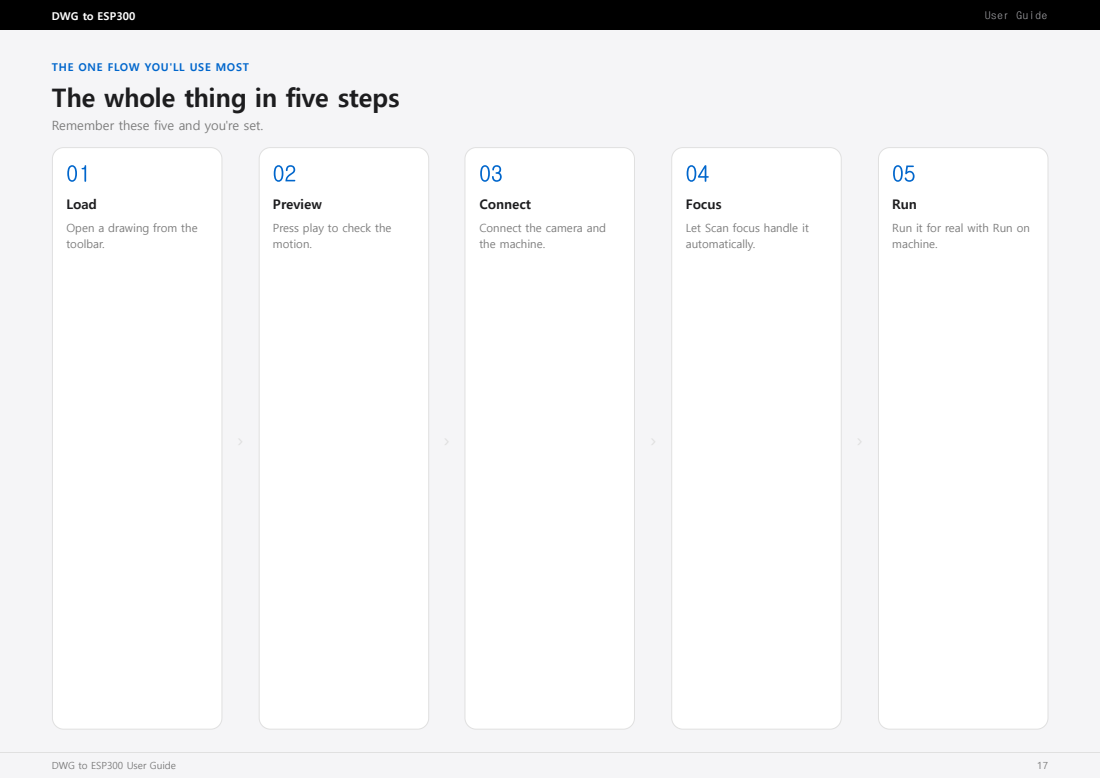
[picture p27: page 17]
Load; Preview; Connect; Focus; Run

THE ONE FLOW YOU'LL USE MOST

Remember these five and you're set.

Open a drawing from the
toolbar.

Press play to check the
motion.

Connect the camera and
the machine.

Let Scan focus handle it
automatically.

Run it for real with Run on
machine.

GOOD TO KNOW

# Tips for working faster

### 1 Leave Active turned on

It re-focuses automatically every time you move, so you don't have to click it yourself.

### 2 Start in practice mode

Get comfortable with Dry run turned on first, then turn it off once you're ready to move for real.

### 3 The keyboard is often faster

Arrow keys move it, Page Up/Down changes height, and Space stops everything instantly.

### 4 Practice with the sample first

No drawing ready yet? Use the sample drawing to get the whole flow down first.

### 5 Don't let the computer sleep mid-job

Sleep mode can drop the connection.

### 6 When in doubt, stop first

If you're ever unsure, hit STOP (emergency stop) first and figure out what's going on. There's nothing you can't undo by stopping.

TROUBLESHOOTING

# If this happens, try this

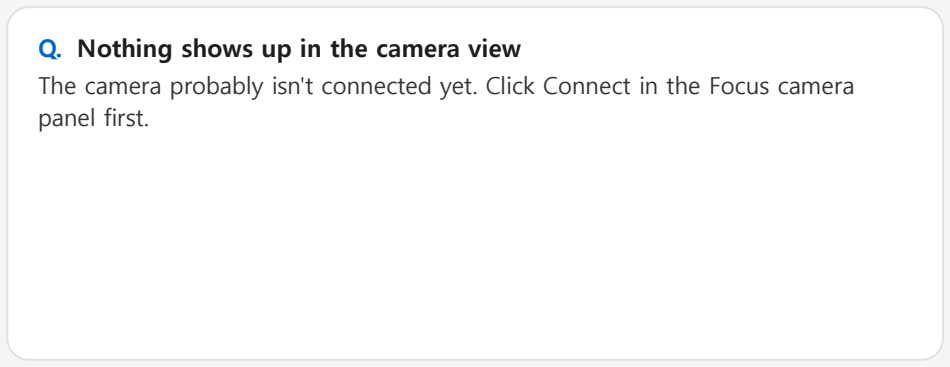
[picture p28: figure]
Q. Nothing shows up in the camera view; panel first.

The camera probably isn't connected yet. Click Connect in the Focus camera

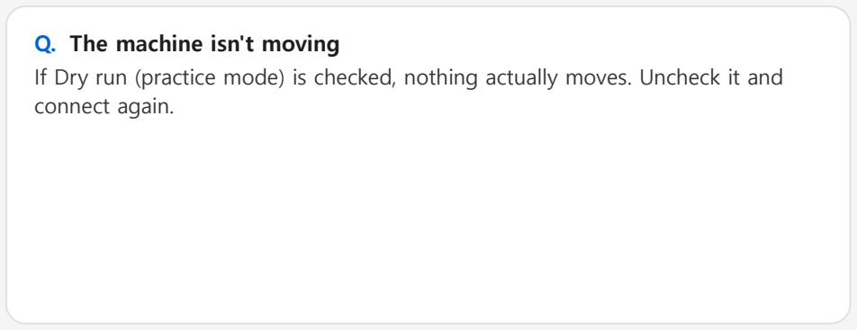
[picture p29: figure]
Q. The machine isn't moving; connect again.

If Dry run (practice mode) is checked, nothing actually moves. Uncheck it and

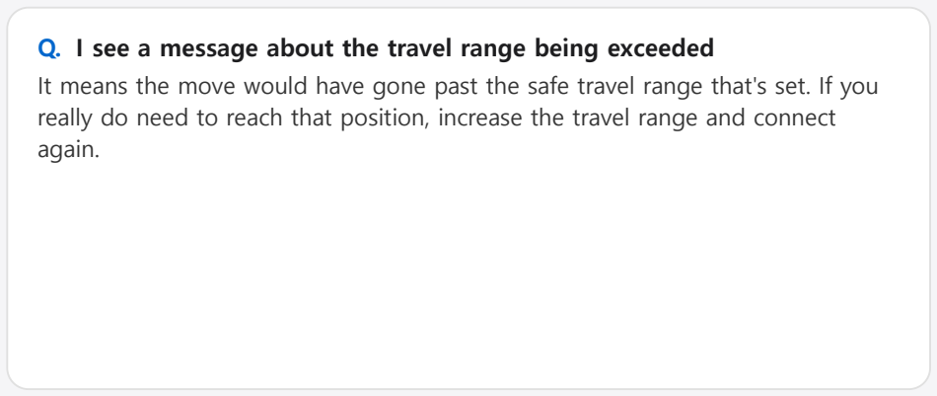
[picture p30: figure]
again.

Q. I see a message about the travel range being exceeded
It means the move would have gone past the safe travel range that's set. If you really do need to reach that position, increase the travel range and connect

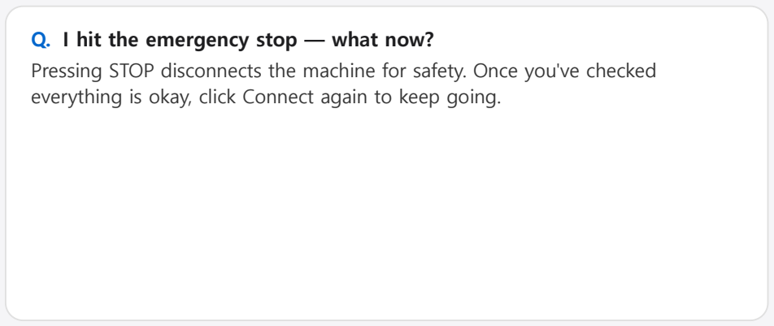
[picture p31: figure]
Q. I hit the emergency stop — what now?

Pressing STOP disconnects the machine for safety. Once you've checked everything is okay, click Connect again to keep going.

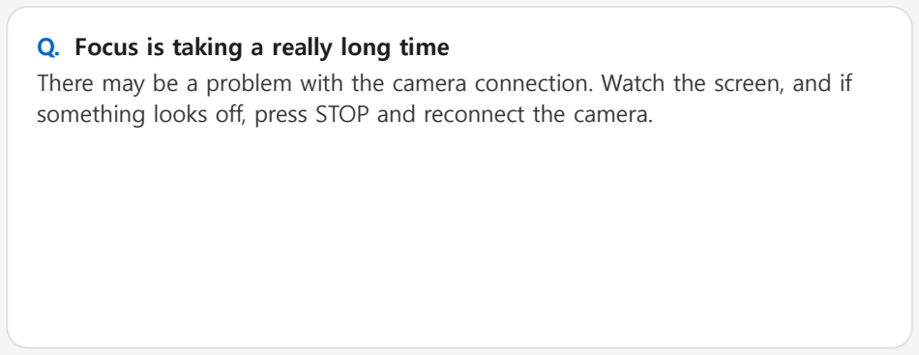
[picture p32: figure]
Q. Focus is taking a really long time

There may be a problem with the camera connection. Watch the screen, and if something looks off, press STOP and reconnect the camera.

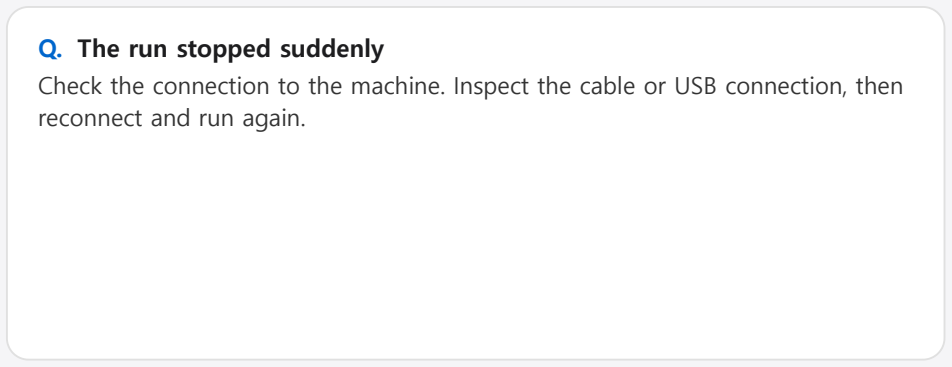
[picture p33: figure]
Q. The run stopped suddenly; reconnect and run again.

Check the connection to the machine. Inspect the cable or USB connection, then

CLOSING

# You're ready to go

From loading a drawing, to focusing with the camera, to running the real machine — just follow the order laid out in this guide. If you ever get stuck, flip back to the matching page any time.

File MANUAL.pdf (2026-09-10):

# DWG to ESP300

# 레이저 스테이지 랩 리그

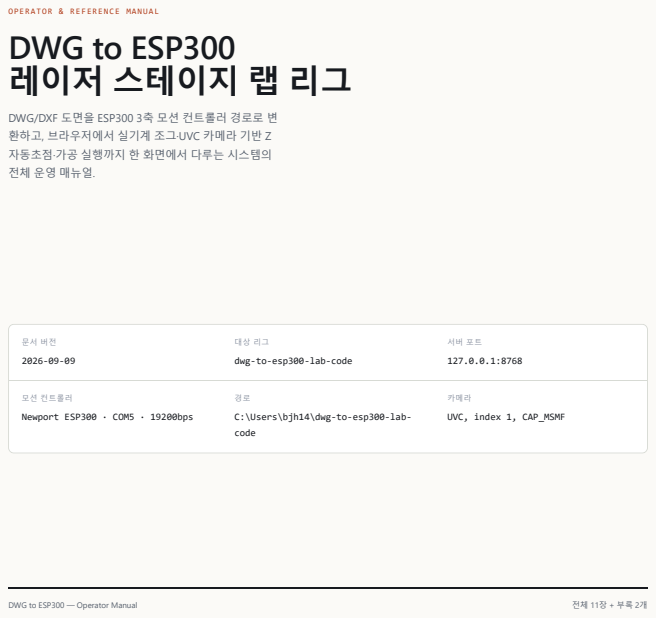
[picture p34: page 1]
DWG to ESP300 — Operator Manual

OPERATOR & REFERENCE MANUAL

DWG/DXF 도면을 ESP300 3축 모션 컨트롤러 경로로 변
환하고, 브라우저에서 실기계 조그·UVC 카메라 기반 Z
자동초점·가공 실행까지 한 화면에서 다루는 시스템의
전체 운영 매뉴얼.

문서 버전 2026-09-09 | 대상 리그 dwg-to-esp300-lab-code | 서버 포트 127.0.0.1:8768

모션 컨트롤러 Newport ESP300 · COM5 · 19200bps | 경로 C:\Users\bjh14\dwg-to-esp300-lab-code | 카메라 UVC, index 1, CAP_MSMF

목차

## 01 시스템 개요와 아키텍처

## 02 시작하기 — 서버 실행과 첫 연결

## 03 화면 구성 — Toolbar & Planner

## 04 화면 구성 — Manual Jog 패널

## 05 화면 구성 — Focus Camera & Autofocus 패널

## 06 자동초점 알고리즘 상세

## 07 가공 실행 — Run on Machine

## 08 HTTP API 레퍼런스

## 09 Standalone 스크립트 레퍼런스

## 10 자동 수집 데이터 & 로그

## 11 안전장치 전체 목록

A | 부록 A — 트러블슈팅
B | 부록 B — 튜닝 상수 전체 표

# 01 시스템 개요와 아키텍처

두 개의 독립된 코드 경로가 이 리그를 이룬다 — 하나는 도면을 오프라인 스크립트로 굽는 컴파일러, 하나는 실기계를 브라우저에서 직접 조작하는 서버.

## 1.1 전체 파이프라인

### 25mm 안팎의 작은 부품 도면(DWG/DXF)을 고정빔·이동유리 방식 레이저 스테이지의 이동 명령으로 변환하는 것이 목적. 두 경로:

dwg_to_esp300.py — standalone CLI 변환기. ezdxf 로 도면을 파싱하고 필터링·회전·스케일·정렬한 뒤, ESP300 네이티브 ASCII 명령어( PA , PR , VA , MO , MF , TP )로 스테이지를 직접 구동하는 완전한 standalone .py 스크립트를 f-string 템플릿으로 생성한다. G-code나 명령 리스트 파일이 아니라 진짜 실행 가능한 파이썬 코드 한 벌을 뽑아낸다는 점이 핵심. Jupyter 노트북 버전과 SVG 미리보기도 같이 만들 수 있음.

visualizer_server.py — ThreadingHTTPServer 기반 로컬 웹 앱. dwg_to_esp300.py 의 함수들( LaserPath , apply_fit_scale , cap_scale_to_circle , extract_paths , generate_esp300_script 등)을 그대로 import해서 브라우저 UI로 계획(planning)과 실기계 라이브 구동(조그, 카메라 초점 보정, "Run on
machine")을 동시에 제공.

## 1.2 visualizer_server.py 핵심 클래스 4개

클래스 | 역할
JogController | ESP300 시리얼 통신 전체 — 연결/해제, 축별 move() , 절대좌표 goto() , home() / set_local_home() , E-STOP, 백그라운드 스레드로 전체 경로를 실행하는 run_plan() / _run_worker() .
CameraController | 백그라운드 UVC 캡처 스레드(OpenCV). MJPEG 스트림과 blob 밝기 상태를 동시에 제공. locate_bright_regions() 로 red-glow/saturated-core 스팟 추적.
FocusScanner | Z 자동초점 스캔 오케스트레이션. focus_autocal.scan_focus_z() 를 호출하되 move_z 는 JOG.move("z",...) 에, read_brightness 는 카메라 blob score에 직접(HTTP 왕복 없이 in-process로) 연결.
VisualizerHandler | do_GET / do_POST 라우트 테이블(8장) + visualizer/ 정적 파일 서빙.

## 1.3 focus_autocal.py 와의 관계

### focus_autocal.py 는 하드웨어에 대해 아무것도 모르는 재사용 가능한 순수 알고리즘 라이브러리

다 — 카메라/스테이지 콜백을 호출자가 넘겨준다. FocusScanner._run_stage() 가 ESP300 Z-jog와

### 카메라의 실시간 blob score를 scan_focus_z() 에 연결해주는 어댑터 역할. Repo 루트의 run_*.py standalone 스크립트들은 자기 시리얼/카메라 핸들을 새로 열지 않고 이미 켜져 있는

visualizer_server.py 를 HTTP로 조종한다 — ESP300의 COM 포트는 한 번에 하나만 열 수 있고, Jog 패널이 이미 그 연결을 쥐고 있기 때문(9장).

## 1.4 세션 상태

### 도면을 불러오면 SESSIONS: dict[str, dict] (모듈 전역, 메모리 상주, 서버 재시작하면 사라짐)에

uuid.uuid4().hex[:12] 키로 세션 하나가 생긴다. 이후 /api/plan , /api/export 는 전부 이 sessionId 를 참조.

# 02 시작하기 — 서버 실행과 첫 연결

## 2.1 서버 실행

### 바탕화면 바로가기 "DWG to ESP300 열기" 또는 아래를 직접 실행:

C:\Users\bjh14\dwg-to-esp300-lab-code\dwg-esp300-launch.cmd

### 이 배치파일이 하는 일: netstat 로 포트 8768이 이미 열려있는지 확인 → 없으면 python

visualizer_server.py --host 127.0.0.1 --port 8768 을 최소화 창으로 새로 띄움 → 브라우저로 http://127.0.0.1:8768/ 오픈.

포트 주의 — 절대 지키기

## visualizer_server.py 자체의 argparse 기본 포트는 8765다. 8765/8766/8767 세 포트는 이 프로 젝트와 무관한 개인 study 서버(sakurai/goldstein/signals)가 영구적으로 쓰는 포트라, 이 프로젝트를

그 위에서 절대 띄우면 안 된다. dwg-esp300-launch.cmd 는 올바르게 --port 8768 로 덮어써서 실 행함 — 반드시 이 launcher로 실행할 것.

같은 repo 루트의 launch_dwg_to_esp300.ps1 은 예전 버전 launcher로 $port = 8766 이 박혀있던

## 것을 이번 매뉴얼 작성 중 발견해서 8768로 고쳐놓음(2026-09-09). 앞으로도 .cmd launcher를 표준

으로 쓰고 .ps1 은 참고용으로만 둘 것.

## 2.2 첫 연결 순서

전원관리 주의

### PC가 절전모드로 들어가면 USB-시리얼 연결이 끊기거나 COM 포트 번호가 바뀔 수 있음. 조그/실행

중에는 Windows 절전을 꺼둘 것.

Jog 탭에서 ESP300 연결. Port COM5 , Baud 19200 이 기본값. Dry-run 체크박스를 반드시 해제해야 실제 이동이 일어남 — 체크된 채로는 서버가 self.dry_run 이 True라 모든 시리얼 write가 조용히 no-op된다. X-Y range(mm)·Z range(mm)도 이때 지정 — 이게 곧 3장/11장에서 다루는 하드 안전 한도가 된다.

1

Focus camera 패널에서 카메라 연결. Index 기본값 1( camera_probe.py 로 먼저 어느 인덱스가 맞는 UVC 장치인지 확인해두면 좋음, 9장). MJPEG 스트림이 뜨고 blob 오버레이(초록=red glow, 노랑=saturated core, 자홍 십자=합성 타깃)가 보이면 정상.

2

## 도면 로드. Toolbar에서 파일 선택 또는 경로 입력, "Open path"/"Open file". 샘플이 필요하면 "Sample" 버튼

( C:\Users\bjh14\Downloads\adjust25design.dwg 가 있어야 함).

3

## 초점 스캔. Autofocus 패널 "Scan focus" — 처음이면 wide+narrow 2단, 이후엔 narrow만. ⁴

## 필요하면 "Run on machine". 7장 참고 — 실행 전 확인 다이얼로그가 뜸. ⁵

# 03 화면 구성 — Toolbar & Planner

aside.panel (지표 타일 + 카메라/초점 패널 + Jog/Shapes/Paths 탭).

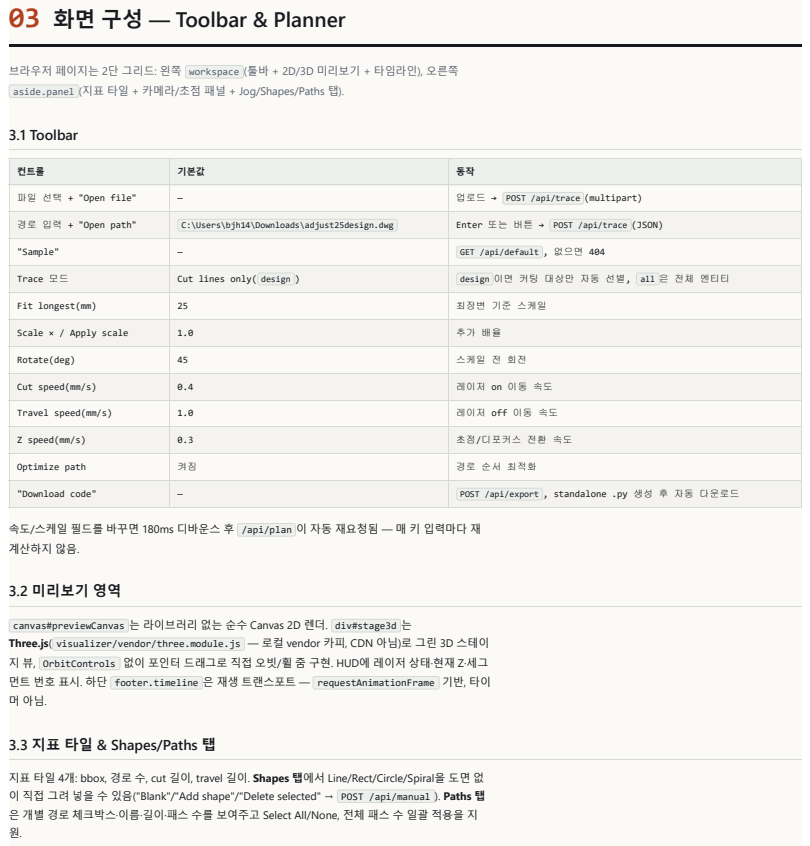
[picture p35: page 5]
3.1 Toolbar; 3.2 미리보기 영역

브라우저 페이지는 2단 그리드: 왼쪽 workspace (툴바 + 2D/3D 미리보기 + 타임라인), 오른쪽

컨트롤 | 기본값 | 동작

파일 선택 + "Open file" | — | 업로드 → POST /api/trace (multipart)

경로 입력 + "Open path" | C:\Users\bjh14\Downloads\adjust25design.dwg | Enter 또는 버튼 → POST /api/trace (JSON)

"Sample" | — | GET /api/default , 없으면 404

Trace 모드 | Cut lines only( design ) | design 이면 커팅 대상만 자동 선별, all 은 전체 엔티티

Fit longest(mm) | 25 | 최장변 기준 스케일

Scale × / Apply scale | 1.0 | 추가 배율

Rotate(deg) | 45 | 스케일 전 회전

Cut speed(mm/s) | 0.4 | 레이저 on 이동 속도

Travel speed(mm/s) | 1.0 | 레이저 off 이동 속도

Z speed(mm/s) | 0.3 | 초점/디포커스 전환 속도

Optimize path | 켜짐 | 경로 순서 최적화

"Download code" | — | POST /api/export , standalone .py 생성 후 자동 다운로드

속도/스케일 필드를 바꾸면 180ms 디바운스 후 /api/plan 이 자동 재요청됨 — 매 키 입력마다 재
계산하지 않음.

canvas#previewCanvas 는 라이브러리 없는 순수 Canvas 2D 렌더. div#stage3d 는
Three.js( visualizer/vendor/three.module.js — 로컬 vendor 카피, CDN 아님)로 그린 3D 스테이
지 뷰, OrbitControls 없이 포인터 드래그로 직접 오빗/휠 줌 구현. HUD에 레이저 상태·현재 Z·세그
먼트 번호 표시. 하단 footer.timeline 은 재생 트랜스포트 — requestAnimationFrame 기반, 타이

3.3 지표 타일 & Shapes/Paths 탭

지표 타일 4개: bbox, 경로 수, cut 길이, travel 길이. Shapes 탭에서 Line/Rect/Circle/Spiral을 도면 없
이 직접 그려 넣을 수 있음("Blank"/"Add shape"/"Delete selected" → POST /api/manual ). Paths 탭
은 개별 경로 체크박스·이름·길이·패스 수를 보여주고 Select All/None, 전체 패스 수 일괄 적용을 지

# 04 화면 구성 — Manual Jog 패널

## 4.1 연결 필드

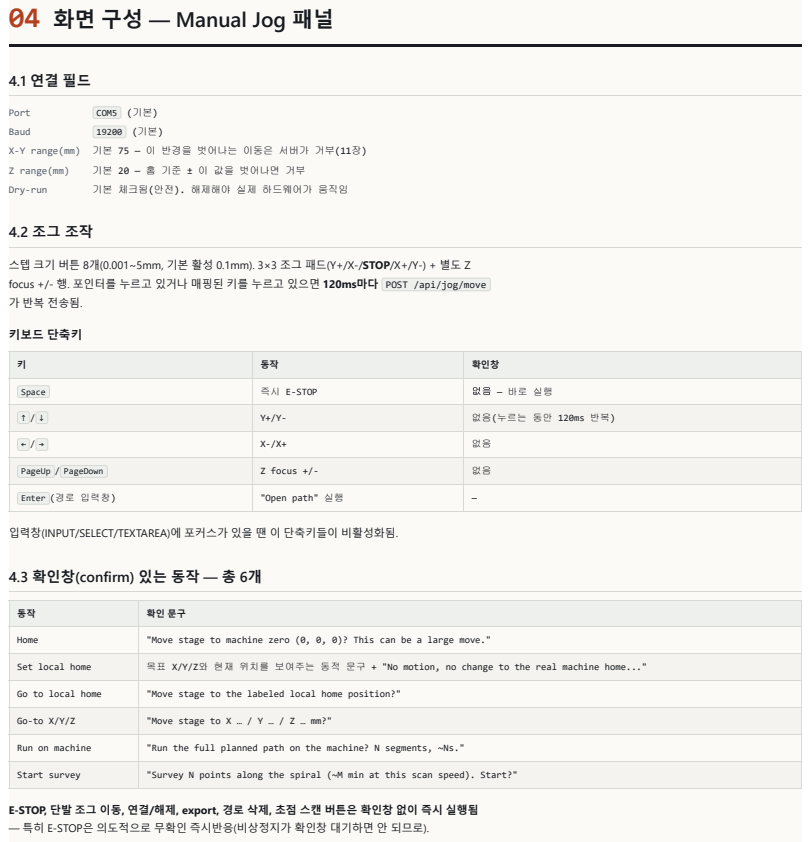
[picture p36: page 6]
Port; COM5 (기본); Baud; Z range(mm); 기본 20 — 홈 기준 ± 이 값을 벗어나면 거부; Dry-run; 기본 체크됨(안전). 해제해야 실제 하드웨어가 움직임; 키보드 단축키

X-Y range(mm) 기본 75 — 이 반경을 벗어나는 이동은 서버가 거부(11장)

스텝 크기 버튼 8개(0.001~5mm, 기본 활성 0.1mm). 3×3 조그 패드(Y+/X-/STOP/X+/Y-) + 별도 Z
focus +/- 행. 포인터를 누르고 있거나 매핑된 키를 누르고 있으면 120ms마다 POST /api/jog/move
가 반복 전송됨.

키 | 동작 | 확인창

Space | 즉시 E-STOP | 없음 — 바로 실행

↑ / ↓ | Y+/Y- | 없음(누르는 동안 120ms 반복)

PageUp / PageDown | Z focus +/- | 없음

Enter (경로 입력창) | "Open path" 실행 | —

입력창(INPUT/SELECT/TEXTAREA)에 포커스가 있을 땐 이 단축키들이 비활성화됨.

4.3 확인창(confirm) 있는 동작 — 총 6개

Home | "Move stage to machine zero (0, 0, 0)? This can be a large move."

Set local home | 목표 X/Y/Z와 현재 위치를 보여주는 동적 문구 + "No motion, no change to the real machine home..."

Go to local home | "Move stage to the labeled local home position?"

Go-to X/Y/Z | "Move stage to X … / Y … / Z … mm?"

Run on machine | "Run the full planned path on the machine? N segments, ~Ns."

Start survey | "Survey N points along the spiral (~M min at this scan speed). Start?"

E-STOP, 단발 조그 이동, 연결/해제, export, 경로 삭제, 초점 스캔 버튼은 확인창 없이 즉시 실행됨
— 특히 E-STOP은 의도적으로 무확인 즉시반응(비상정지가 확인창 대기하면 안 되므로).

# 05 화면 구성 — Focus Camera & Autofocus 패널

# 5.1 Focus Camera 패널

Index 입력(기본 1) + Connect/Disconnect. img#cameraStream 이 /api/camera/stream (MJPEG,
15fps)을 그대로 표시. 스트림 위 클릭 = POST /api/camera/select-target 로 blob 추적 앵커를 그 위치로 강제 이동(여러 후보 blob 중 특정 것을 지목할 때). 밝기/스팟 수치가 실시간 갱신.

# 5.2 Autofocus 패널

## "Scan focus"(기본) / "Wide rescan" / "Narrow only" 버튼 → POST /api/focus/scan . "Active" 체크

### 박스 → POST /api/focus/active — 켜두면 X/Y가 움직일 때마다 600ms 디바운스 후 자동으로

narrow 재스캔이 돈다(6장 4절).

### 실시간 SVG 차트( svg#focusChart )가 스캔 곡선을 그리고, 드래그로 범위를 선택하면 그 구간으로

커스텀 스캔을 다시 돌릴 수 있음.

## Custom scan 하위 패널

direction(both/down/up) · range(mm) · step(mm) · settle(s) 필드 → | POST
/api/focus/scan/custom | . 특정 구간만 다시 훑거나, 속도-신뢰성 트레이드오프를 직접 조정할 때.

## Timing check 하위 패널

## "Verify timing (slow vs fast)" 버튼 → POST /api/focus/latency-check . 아주 느리고 여유로운 기준

### 스캔과 실제 production 타이밍 스캔을 같은 창에서 두 번 돌려 피크 위치 차이( deltaMm )와 그걸 "지

연 시간"으로 환산한 impliedLagS 를 보여줌 — 6장 5절에서 이 지표의 한계를 다룸.

## Spiral survey 하위 패널

narrow-only 토글 + "Survey spiral path"/"Stop survey" → POST /api/focus/survey/start|stop .

### X/Y 웨이포인트를 순서대로 돌며 각 지점에서 초점 스캔 → (x,y)→Z 오프셋/밝기 맵을 만듦. SVG로 진

행 상황 표시.

SURVEY 실행 전 확인

### 2026-09-09 세션에서 survey 도중 카메라 프리즈 버그로 한 waypoint에서 20분 넘게 멈춘 사고가 있 었음(10장/11장). 지금은 watchdog이 코드에 들어가 있지만 아직 실기계 재검증 전 — survey를 돌릴

땐 옆에서 지켜보고, 이상하면 Space 로 즉시 E-STOP.

# 06 자동초점 알고리즘 상세

focus_autocal.py 가 순수 알고리즘, visualizer_server.py 의 FocusScanner 가 이 리그 하드웨 어에 맞춘 어댑터.

## 6.1 scan_focus_z() — 핵심 스캔 함수

scan_focus_z(move_z, fire_pulse, read_brightness, center_z, range_mm=0.3, step_mm=0.02, settle_s=0.05, direction="both", adaptive_rise_ratio=1.5, adaptive_subdivisions=4) -> FocusScanResult

### 노이즈에 강건함이 필요하면(전체 이웃을 다 보므로) 이 함수를, 속도가 우선이고 곡선이 매끈하다고

확신하면 아래 hill_climb_focus_z() 를 쓴다.

## 6.2 다른 두 진입점

함수 | 용도
calibrate_surface() | 표면 하나당 한 번 호출하는 고수준 진입점. ROI를 baseline/pulse diff로 자동 재탐지한 뒤 scan_focus_z 에 위임. 카메라 각도가 바뀌 어도 다시 호출만 하면 스스로 재조정.
hill_climb_focus_z() | 양방향 언덕오르기. 더 밝으면 같은 방향·같은 스텝 유지, 아니면 방향 반전+스텝 절반. fit_used 는 항상 False. 6장 8절 PID 검증 결 과와 같은 이유로, 잔여 노이즈가 있는 지금 곡선에서는 국소 최댓값에 갇히기 쉬움 — 곡선이 이미 매끈하다고 알려진 상황(작은 알려진 drift 재보정)에서만 권장.

FocusScanner._run_stage() 는 scan_focus_z 를 직접 부른다 — calibrate_surface 나 focus_autocal 의 BrightnessCamera /ROI 자동탐지는 안 쓴다. 실카메라의 blob 추적
( locate_bright_regions )이 이미 서버 쪽에 있기 때문.

## 6.3 밝기 스코어 — locate_bright_regions()

visualizer_server.py 에만 있는 함수( focus_autocal.py 엔 없음). 프레임에서 red-hue 블롭과

## saturated-core(회색값≥250) 블롭을 각각 찾고, core가 안쪽에 들어있는 red 블롭을 "진짜 타깃 후보"

### 페어로 취급. 후보가 여럿이면 이전 프레임에서 골랐던 위치( prior_xy )에 가장 가까운 것으로 연속

성 유지. score는 그 페어 마스크 위 픽셀 값의 합.

# 6.4 2026-09-09 수정 — 왜 곡선이 들쑥날쑥했나

근본 원인

## 페어(red+core)를 못 찾으면 score가 정확히 0.0으로 떨어졌음 — 연속 감쇠가 아니라 이진 on/off. 실

측: ±1.0mm/0.01mm 스캔 417샘플 중 142개(34.1%)가 정확히 0.0.

수정 두 가지, 둘 다 visualizer_server.py :

coarse sweep. center_z 기준 direction 에 따라 오프셋 목록 생성 — both 는 ±range, down 은 0..-range, up 은 0..+range. ¹

adaptive subdivision. 인접 샘플 쌍의 밝기 비율이 adaptive_rise_ratio (1.5)를 넘으면 "spike"로 판단해서 그 구간에 adaptive_subdivisions (4)개를 더 촘촘히 찍음 — 빠른 coarse 스캔으로도 좁은 실제 피크를 놓치지 않게 하는 핵심 트릭.

2

## 피크 선택. coarse+refined 샘플 전체에서 최댓값 위치를 찾음. ³

### 파라볼릭 피팅. 그 피크가 양쪽에 이웃을 갖고 있으면 세 점을 지나는 포물선의 꼭짓점을 계산해 best_z 로 사용(등간격 아니어도 정확한 공식) — 서브스텝

해상도. 아니면 원samples 중 최댓값 위치 그대로 사용.

4

### FOCUS_BRIGHTNESS_SAMPLES 2→5, 평균을 mean에서 median으로. 홀수 5장 중 최대 2장이 드롭아웃 나도 안 흔들림. ¹

locate_bright_regions() 가 페어를 못 찾을 때, 0.0 대신 core 없이 가장 그럴듯한 red 블롭 단독 score로 대체. 페어 score는 core 픽셀까지 더하므로 항상 이 fallback보다 크고, 오탐 없이 곡선이 완만히 이어짐.

2

### 검증: median-of-5 단독으론 0% 못 만듦(초점 먼 구간은 애초에 절반 넘게 진짜 드롭아웃이라

## median도 0 반환) — fallback을 더해야 0.0이 완전히 사라지고 total variation/peak가 18.18→15.22로

줄어듦.

## 6.5 PID 제어기법 타당성 검증

### 실측 곡선을 보간해 두 컨트롤러를 오프라인 시뮬레이션함(2026-09-09):

방식 | 시작점 | 결과
Naive brightness-PID error = target − 측정 밝기 | z₀=−0.40 | +0.575mm (참값에서 +0.275mm 오차)
| z₀=+0.90 | +18.5mm로 폭주
Slope-seeking P-control error = 국소 기울기 | z₀=−0.40 | −0.58mm (잔여 스파이크에 걸림)
| z₀=+0.90 | +0.855mm (잔여 스파이크에 걸림)

### 결론: PID는 이 문제 구조에 안 맞음. 밝기-오차 PID는 피크 좌우 어느 쪽에 있는지에 따라 필요한 이 동 방향의 부호가 반대인데, 고정 부호 게인은 이걸 구분 못 해 피크를 지나쳐 있으면 오차를 계속 같 은 방향으로 키우며 폭주함. 부호가 명확한 slope-seeking조차 6.3절의 잔여 스파이크(9장)에 걸려 국

소 최댓값에 갇힘. 지금 쓰는 전체 그리드 스캔 + 파라볼릭 피팅이 이 노이즈 특성에 더 강건함.

# 07 가공 실행 — Run on Machine

# 7.1 흐름

Jog 탭 안 "Run planned path on machine" 버튼( #jogRunButton ) → 확인창 → | POST
/api/run/start | (현재 plan의 segments 전달) → JOG.run_plan() 이 백그라운드 스레드
( _run_worker ) 시작 → 프론트가 GET /api/run/status 를 200ms마다 폴링해서 진행률 표시. "Stop"( #jogRunStopButton ) → POST /api/run/stop .

## 7.2 세그먼트 실행 방식

### 세그먼트마다: 목표까지 걸릴 시간( duration )으로 축별 속도를 역산 → nVA (속도 설정) → nPA (절 대 위치 이동) 전송 → 도착 확인 폴링. 타임아웃은 max(3.0, duration*4 + 2.0) 초, 허용오차 0.02mm. 타임아웃 안에 못 들어오면 그 자리에서 즉시 예외 — 예전엔 타임아웃을 도착으로 오인하 고 계속 진행했었는데, 그게 축 stall/fault를 놓치는 원인이라 지금은 바로 멈추고

_fault_context() (ESP300 에러 버퍼/축 에러 상태)를 붙여서 보고함.

# 7.3 "이유 없이 끊기는" 문제 — 2026-09-09 수정

### 원인 두 가지, 둘 다 코드로 고침(실기계 재검증 전):

### "입력초과"는 코드상 매 구간 도착 확인 후에만 다음 구간으로 넘어가는 구조라 무한정 쌓이는 종류

는 아니었음.

중복 폴링. 백그라운드 _poll_loop (위치 갱신용 heartbeat)가 run 중에도 계속 같은 축을 TP 쿼리하고 있었음 — _run_worker 자신도 도착 확인을 위해 같은 축을 폴링하므로 트래픽이 사실상 두 배. 수정: run이 진행 중이면 _poll_loop 는 자기 폴링을 쉼.

1

일회성 통신 오류 무재시도. _read_axis_position() 이 진짜 serial.SerialException 을 만나면 재시도 없이 즉시 전체 연결을 끊었음(응답 형식이 이상 할 때만 재시도하고 있었음). 수정: 같은 재시도 예산( JOG_TP_RETRIES =5회) 안에서 통신 오류도 같이 재시도.

2

# 08 HTTP API 레퍼런스

# 8.1 GET

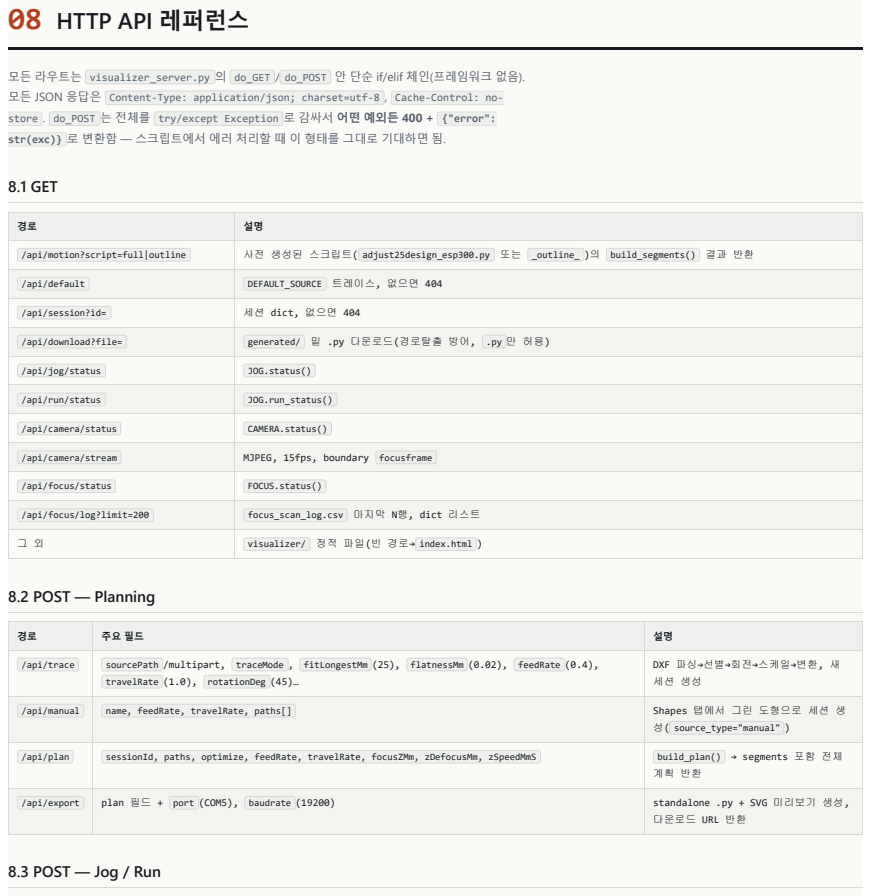
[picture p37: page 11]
8.2 POST — Planning

모든 라우트는 visualizer_server.py 의 do_GET / do_POST 안 단순 if/elif 체인(프레임워크 없음).
모든 JSON 응답은 Content-Type: application/json; charset=utf-8 , Cache-Control: no-
store . do_POST 는 전체를 try/except Exception 로 감싸서 어떤 예외든 400 + {"error":
str(exc)} 로 변환함 — 스크립트에서 에러 처리할 때 이 형태를 그대로 기대하면 됨.

/api/motion?script=full|outline | 사전 생성된 스크립트( adjust25design_esp300.py 또는 _outline_ )의 build_segments() 결과 반환

/api/default | DEFAULT_SOURCE 트레이스, 없으면 404

/api/session?id= | 세션 dict, 없으면 404

/api/download?file= | generated/ 밑 .py 다운로드(경로탈출 방어, .py 만 허용)

/api/jog/status | JOG.status()

/api/run/status | JOG.run_status()

/api/camera/status | CAMERA.status()

/api/camera/stream | MJPEG, 15fps, boundary focusframe

/api/focus/status | FOCUS.status()

/api/focus/log?limit=200 | focus_scan_log.csv 마지막 N행, dict 리스트

그 외 | visualizer/ 정적 파일(빈 경로→ index.html )

/api/trace | sourcePath /multipart, traceMode , fitLongestMm (25), flatnessMm (0.02), feedRate (0.4), travelRate (1.0), rotationDeg (45)… | DXF 파싱→선별→회전→스케일→변환, 새 세션 생성

/api/manual | name, feedRate, travelRate, paths[] | Shapes 탭에서 그린 도형으로 세션 생 성( source_type="manual" )

/api/plan | sessionId, paths, optimize, feedRate, travelRate, focusZMm, zDefocusMm, zSpeedMmS | build_plan() → segments 포함 전체 계획 반환

/api/export | plan 필드 + port (COM5), baudrate (19200) | standalone .py + SVG 미리보기 생성, 다운로드 URL 반환

8.3 POST — Jog / Run

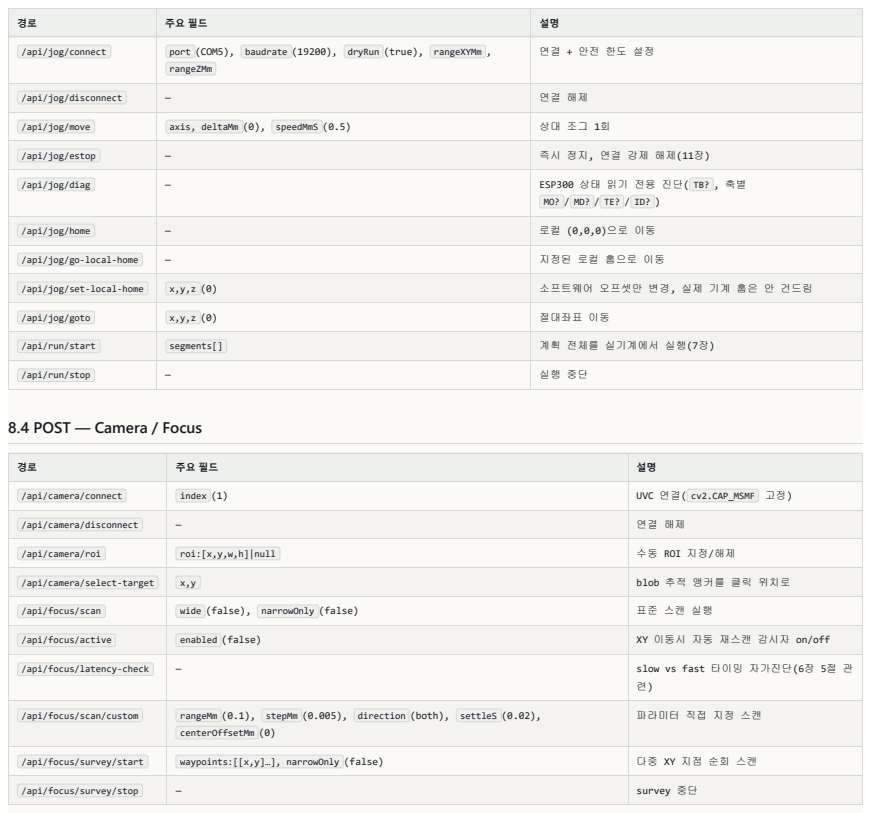
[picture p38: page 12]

/api/jog/connect | port (COM5), baudrate (19200), dryRun (true), rangeXYMm , rangeZMm | 연결 + 안전 한도 설정

/api/jog/disconnect | — | 연결 해제

/api/jog/move | axis, deltaMm (0), speedMmS (0.5) | 상대 조그 1회

/api/jog/estop | — | 즉시 정지, 연결 강제 해제(11장)

/api/jog/diag | — | ESP300 상태 읽기 전용 진단( TB? , 축별 MO? / MD? / TE? / ID? )

/api/jog/home | — | 로컬 (0,0,0)으로 이동

/api/jog/go-local-home | — | 지정된 로컬 홈으로 이동

/api/jog/set-local-home | x,y,z (0) | 소프트웨어 오프셋만 변경, 실제 기계 홈은 안 건드림

/api/jog/goto | x,y,z (0) | 절대좌표 이동

/api/run/start | segments[] | 계획 전체를 실기계에서 실행(7장)

/api/run/stop | — | 실행 중단

8.4 POST — Camera / Focus

/api/camera/connect | index (1) | UVC 연결( cv2.CAP_MSMF 고정)

/api/camera/disconnect | — | 연결 해제

/api/camera/roi | roi:[x,y,w,h]|null | 수동 ROI 지정/해제

/api/camera/select-target | x,y | blob 추적 앵커를 클릭 위치로

/api/focus/scan | wide (false), narrowOnly (false) | 표준 스캔 실행

/api/focus/active | enabled (false) | XY 이동시 자동 재스캔 감시자 on/off

/api/focus/latency-check | — | slow vs fast 타이밍 자가진단(6장 5절 관 련)

/api/focus/scan/custom | rangeMm (0.1), stepMm (0.005), direction (both), settleS (0.02), centerOffsetMm (0) | 파라미터 직접 지정 스캔

/api/focus/survey/start | waypoints:[[x,y]…], narrowOnly (false) | 다중 XY 지점 순회 스캔

/api/focus/survey/stop | — | survey 중단

# 09 Standalone 스크립트 레퍼런스

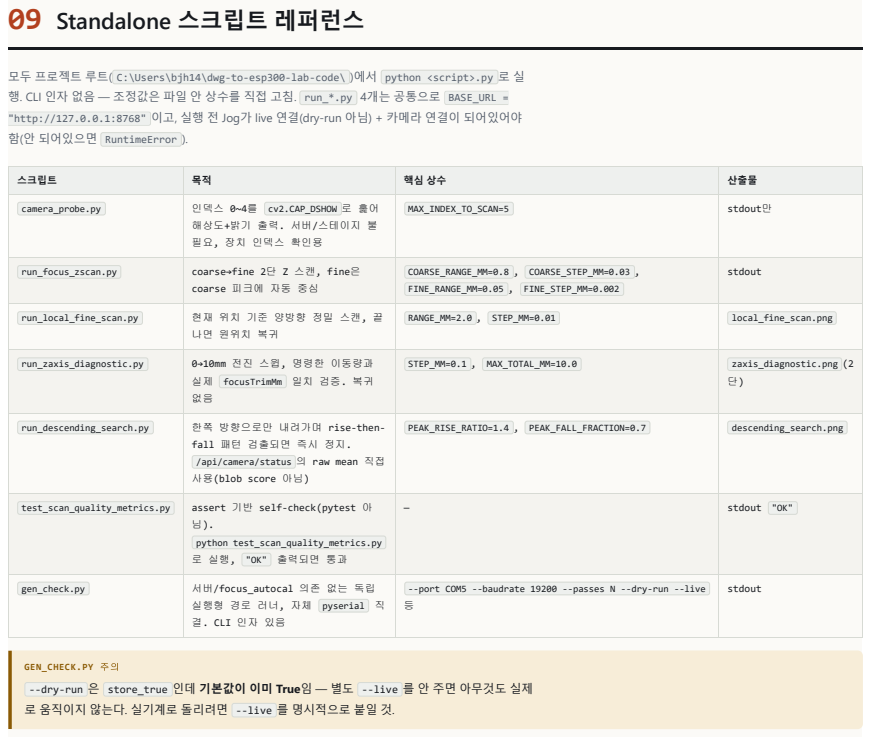
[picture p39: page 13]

모두 프로젝트 루트( C:\Users\bjh14\dwg-to-esp300-lab-code\ )에서 python <script>.py 로 실
행. CLI 인자 없음 — 조정값은 파일 안 상수를 직접 고침. run_*.py 4개는 공통으로 BASE_URL =
"http://127.0.0.1:8768" 이고, 실행 전 Jog가 live 연결(dry-run 아님) + 카메라 연결이 되어있어야
함(안 되어있으면 RuntimeError ).

스크립트 | 목적 | 핵심 상수 | 산출물

camera_probe.py | 인덱스 0~4를 cv2.CAP_DSHOW 로 훑어 해상도+밝기 출력. 서버/스테이지 불 필요, 장치 인덱스 확인용 | MAX_INDEX_TO_SCAN=5 | stdout만

run_focus_zscan.py | coarse→fine 2단 Z 스캔, fine은 coarse 피크에 자동 중심 | COARSE_RANGE_MM=0.8 , COARSE_STEP_MM=0.03 , FINE_RANGE_MM=0.05 , FINE_STEP_MM=0.002 | stdout

run_local_fine_scan.py | 현재 위치 기준 양방향 정밀 스캔, 끝 나면 원위치 복귀 | RANGE_MM=2.0 , STEP_MM=0.01 | local_fine_scan.png

run_zaxis_diagnostic.py | 0→10mm 전진 스윕, 명령한 이동량과 실제 focusTrimMm 일치 검증. 복귀 없음 | STEP_MM=0.1 , MAX_TOTAL_MM=10.0 | zaxis_diagnostic.png (2 단)

run_descending_search.py | 한쪽 방향으로만 내려가며 rise-then-fall 패턴 검출되면 즉시 정지. /api/camera/status 의 raw mean 직접 사용(blob score 아님) | PEAK_RISE_RATIO=1.4 , PEAK_FALL_FRACTION=0.7 | descending_search.png

test_scan_quality_metrics.py | assert 기반 self-check(pytest 아 님). python test_scan_quality_metrics.py 로 실행, "OK" 출력되면 통과 | — | stdout "OK"

gen_check.py | 서버/focus_autocal 의존 없는 독립 실행형 경로 러너, 자체 pyserial 직 결. CLI 인자 있음 | --port COM5 --baudrate 19200 --passes N --dry-run --live 등 | stdout

GEN_CHECK.PY 주의
--dry-run 은 store_true 인데 기본값이 이미 True임 — 별도 --live 를 안 주면 아무것도 실제
로 움직이지 않는다. 실기계로 돌리려면 --live 를 명시적으로 붙일 것.

# 10 자동 수집 데이터 & 로그

동 스텝 없음.

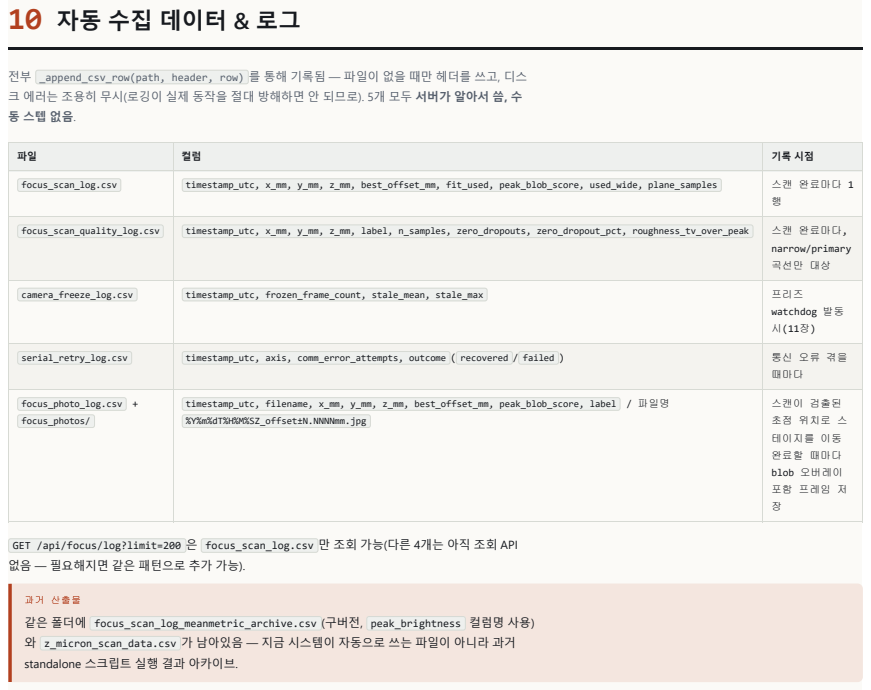
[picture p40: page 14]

전부 _append_csv_row(path, header, row) 를 통해 기록됨 — 파일이 없을 때만 헤더를 쓰고, 디스
크 에러는 조용히 무시(로깅이 실제 동작을 절대 방해하면 안 되므로). 5개 모두 서버가 알아서 씀, 수

focus_scan_log.csv | timestamp_utc, x_mm, y_mm, z_mm, best_offset_mm, fit_used, peak_blob_score, used_wide, plane_samples | 스캔 완료마다 1 행

focus_scan_quality_log.csv | timestamp_utc, x_mm, y_mm, z_mm, label, n_samples, zero_dropouts, zero_dropout_pct, roughness_tv_over_peak | 스캔 완료마다, narrow/primary 곡선만 대상

camera_freeze_log.csv | timestamp_utc, frozen_frame_count, stale_mean, stale_max | 프리즈 watchdog 발동 시(11장)

serial_retry_log.csv | timestamp_utc, axis, comm_error_attempts, outcome ( recovered / failed ) | 통신 오류 겪을 때마다

focus_photo_log.csv + focus_photos/ | timestamp_utc, filename, x_mm, y_mm, z_mm, best_offset_mm, peak_blob_score, label / 파일명 %Y%m%dT%H%M%SZ_offset±N.NNNNmm.jpg | 스캔이 검출된 초점 위치로 스 테이지를 이동 완료할 때마다 blob 오버레이 포함 프레임 저 장

GET /api/focus/log?limit=200 은 focus_scan_log.csv 만 조회 가능(다른 4개는 아직 조회 API
없음 — 필요해지면 같은 패턴으로 추가 가능).

과거 산출물
같은 폴더에 focus_scan_log_meanmetric_archive.csv (구버전, peak_brightness 컬럼명 사용)
와 z_micron_scan_data.csv 가 남아있음 — 지금 시스템이 자동으로 쓰는 파일이 아니라 과거
standalone 스크립트 실행 결과 아카이브.

# 11 안전장치 전체 목록

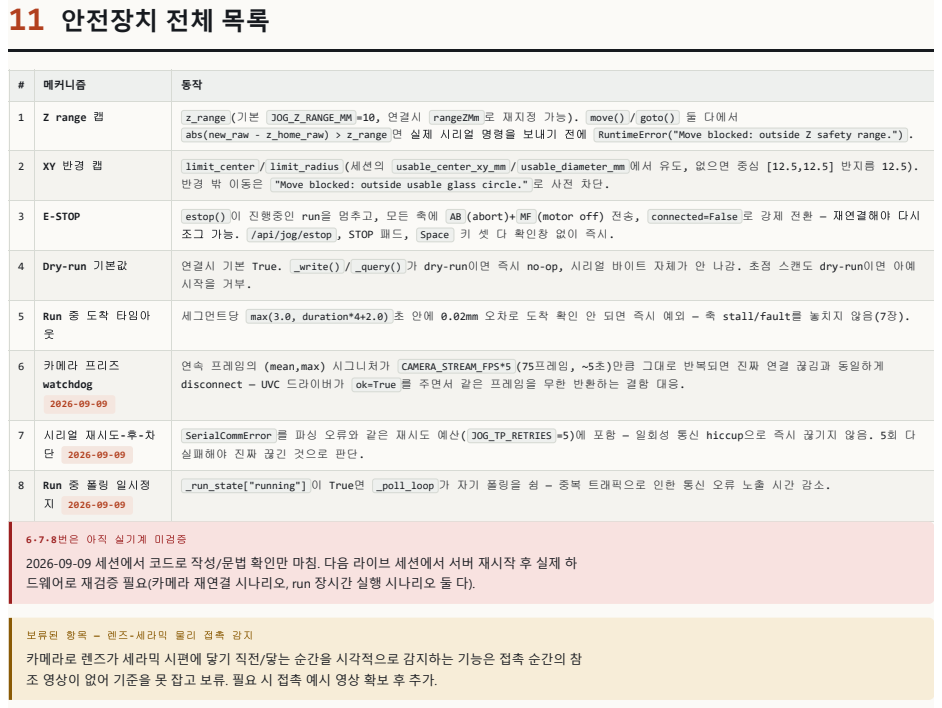
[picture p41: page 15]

# | 메커니즘 | 동작

1 | Z range 캡 | z_range (기본 JOG_Z_RANGE_MM =10, 연결시 rangeZMm 로 재지정 가능). move() / goto() 둘 다에서 abs(new_raw - z_home_raw) > z_range 면 실제 시리얼 명령을 보내기 전에 RuntimeError("Move blocked: outside Z safety range.") .

2 | XY 반경 캡 | limit_center / limit_radius (세션의 usable_center_xy_mm / usable_diameter_mm 에서 유도, 없으면 중심 [12.5,12.5] 반지름 12.5). 반경 밖 이동은 "Move blocked: outside usable glass circle." 로 사전 차단.

3 | E-STOP | estop() 이 진행중인 run을 멈추고, 모든 축에 AB (abort)+ MF (motor off) 전송, connected=False 로 강제 전환 — 재연결해야 다시 조그 가능. /api/jog/estop , STOP 패드, Space 키 셋 다 확인창 없이 즉시.

4 | Dry-run 기본값 | 연결시 기본 True. _write() / _query() 가 dry-run이면 즉시 no-op, 시리얼 바이트 자체가 안 나감. 초점 스캔도 dry-run이면 아예 시작을 거부.

5 | Run 중 도착 타임아 웃 | 세그먼트당 max(3.0, duration*4+2.0) 초 안에 0.02mm 오차로 도착 확인 안 되면 즉시 예외 — 축 stall/fault를 놓치지 않음(7장).

6 | 카메라 프리즈 watchdog 2026-09-09 | 연속 프레임의 (mean,max) 시그니처가 CAMERA_STREAM_FPS*5 (75프레임, ~5초)만큼 그대로 반복되면 진짜 연결 끊김과 동일하게 disconnect — UVC 드라이버가 ok=True 를 주면서 같은 프레임을 무한 반환하는 결함 대응.

7 | 시리얼 재시도-후-차 단 2026-09-09 | SerialCommError 를 파싱 오류와 같은 재시도 예산( JOG_TP_RETRIES =5)에 포함 — 일회성 통신 hiccup으로 즉시 끊기지 않음. 5회 다 실패해야 진짜 끊긴 것으로 판단.

8 | Run 중 폴링 일시정 지 2026-09-09 | _run_state["running"] 이 True면 _poll_loop 가 자기 폴링을 쉼 — 중복 트래픽으로 인한 통신 오류 노출 시간 감소.

6·7·8번은 아직 실기계 미검증
2026-09-09 세션에서 코드로 작성/문법 확인만 마침. 다음 라이브 세션에서 서버 재시작 후 실제 하
드웨어로 재검증 필요(카메라 재연결 시나리오, run 장시간 실행 시나리오 둘 다).

보류된 항목 — 렌즈-세라믹 물리 접촉 감지
카메라로 렌즈가 세라믹 시편에 닿기 직전/닿는 순간을 시각적으로 감지하는 기능은 접촉 순간의 참
조 영상이 없어 기준을 못 잡고 보류. 필요 시 접촉 예시 영상 확보 후 추가.

# A 부록 A — 트러블슈팅

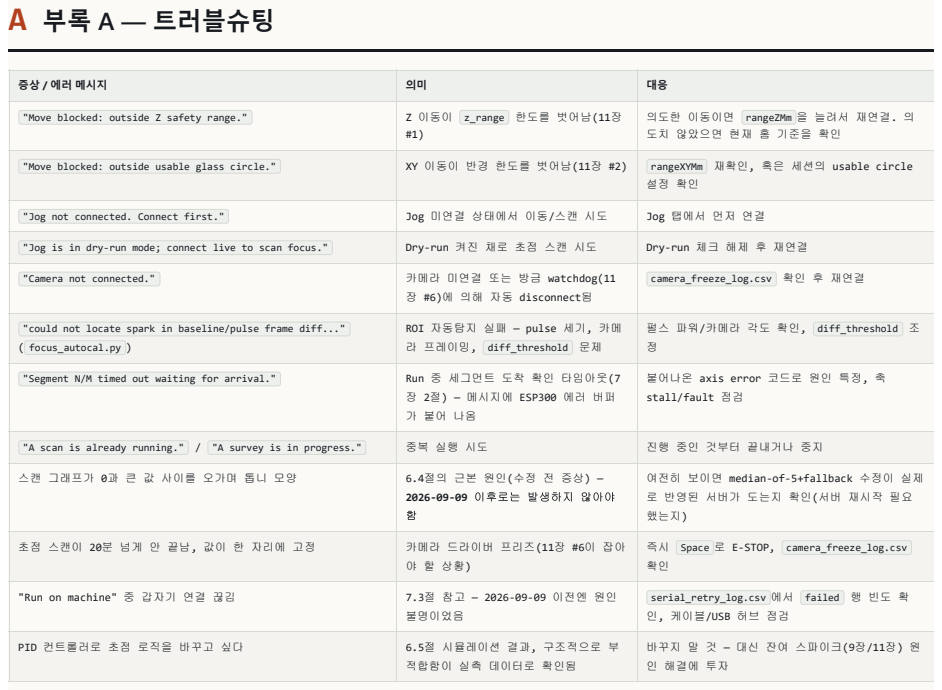
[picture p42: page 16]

증상 / 에러 메시지 | 의미 | 대응

"Move blocked: outside Z safety range." | Z 이동이 z_range 한도를 벗어남(11장 #1) | 의도한 이동이면 rangeZMm 을 늘려서 재연결. 의 도치 않았으면 현재 홈 기준을 확인

"Move blocked: outside usable glass circle." | XY 이동이 반경 한도를 벗어남(11장 #2) | rangeXYMm 재확인, 혹은 세션의 usable circle 설정 확인

"Jog not connected. Connect first." | Jog 미연결 상태에서 이동/스캔 시도 | Jog 탭에서 먼저 연결

"Jog is in dry-run mode; connect live to scan focus." | Dry-run 켜진 채로 초점 스캔 시도 | Dry-run 체크 해제 후 재연결

"Camera not connected." | 카메라 미연결 또는 방금 watchdog(11 장 #6)에 의해 자동 disconnect됨 | camera_freeze_log.csv 확인 후 재연결

"could not locate spark in baseline/pulse frame diff..." ( focus_autocal.py ) | ROI 자동탐지 실패 — pulse 세기, 카메 라 프레이밍, diff_threshold 문제 | 펄스 파워/카메라 각도 확인, diff_threshold 조 정

"Segment N/M timed out waiting for arrival." | Run 중 세그먼트 도착 확인 타임아웃(7 장 2절) — 메시지에 ESP300 에러 버퍼 가 붙어 나옴 | 붙어나온 axis error 코드로 원인 특정, 축 stall/fault 점검

"A scan is already running." / "A survey is in progress." | 중복 실행 시도 | 진행 중인 것부터 끝내거나 중지

스캔 그래프가 0과 큰 값 사이를 오가며 톱니 모양 | 6.4절의 근본 원인(수정 전 증상) — 2026-09-09 이후로는 발생하지 않아야 함 | 여전히 보이면 median-of-5+fallback 수정이 실제 로 반영된 서버가 도는지 확인(서버 재시작 필요 했는지)

초점 스캔이 20분 넘게 안 끝남, 값이 한 자리에 고정 | 카메라 드라이버 프리즈(11장 #6이 잡아 야 할 상황) | 즉시 Space 로 E-STOP, camera_freeze_log.csv 확인

"Run on machine" 중 갑자기 연결 끊김 | 7.3절 참고 — 2026-09-09 이전엔 원인 불명이었음 | serial_retry_log.csv 에서 failed 행 빈도 확 인, 케이블/USB 허브 점검

PID 컨트롤러로 초점 로직을 바꾸고 싶다 | 6.5절 시뮬레이션 결과, 구조적으로 부 적합함이 실측 데이터로 확인됨 | 바꾸지 말 것 — 대신 잔여 스파이크(9장/11장) 원 인 해결에 투자

# B 부록 B — 튜닝 상수 전체 표

# B.1 Jog

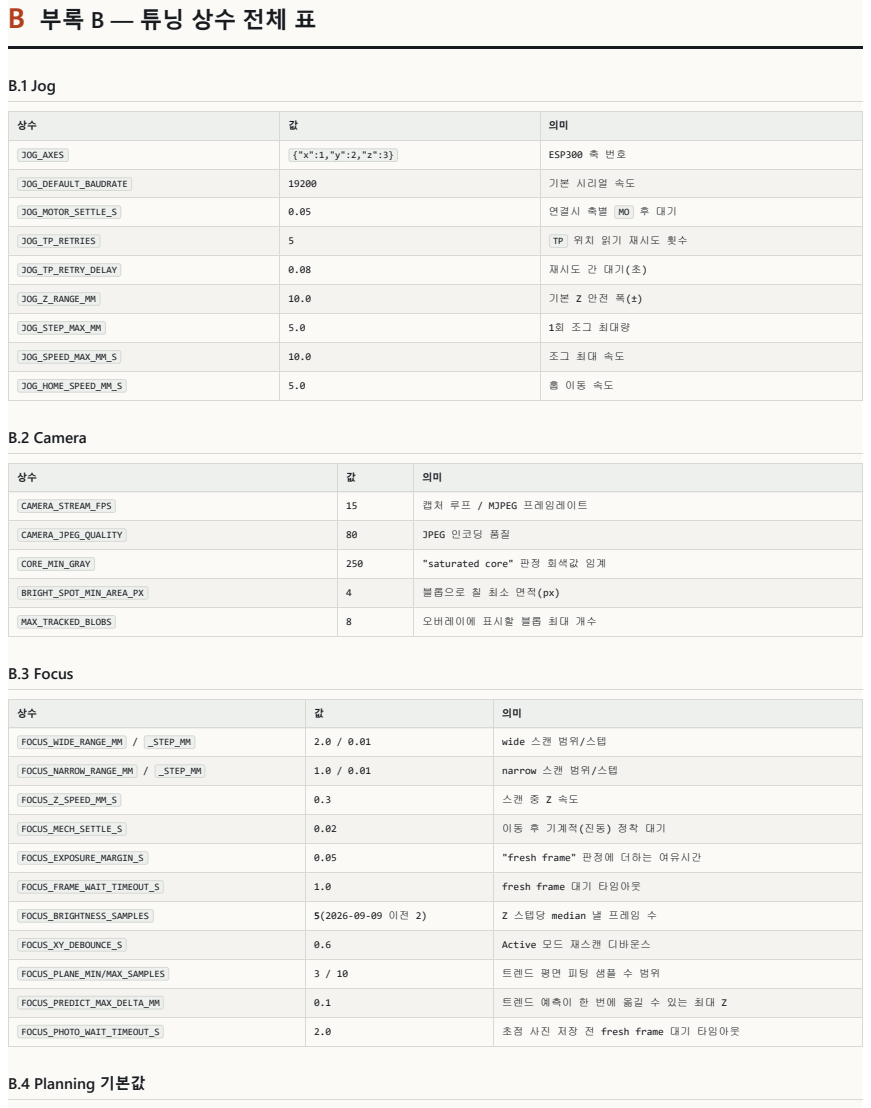
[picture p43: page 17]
B.2 Camera; B.3 Focus; B.4 Planning 기본값

JOG_AXES | {"x":1,"y":2,"z":3} | ESP300 축 번호

JOG_DEFAULT_BAUDRATE | 19200 | 기본 시리얼 속도

JOG_MOTOR_SETTLE_S | 0.05 | 연결시 축별 MO 후 대기

JOG_TP_RETRIES | 5 | TP 위치 읽기 재시도 횟수

JOG_TP_RETRY_DELAY | 0.08 | 재시도 간 대기(초)

JOG_Z_RANGE_MM | 10.0 | 기본 Z 안전 폭(±)

JOG_STEP_MAX_MM | 5.0 | 1회 조그 최대량

JOG_SPEED_MAX_MM_S | 10.0 | 조그 최대 속도

JOG_HOME_SPEED_MM_S | 5.0 | 홈 이동 속도

CAMERA_STREAM_FPS | 15 | 캡처 루프 / MJPEG 프레임레이트

CAMERA_JPEG_QUALITY | 80 | JPEG 인코딩 품질

CORE_MIN_GRAY | 250 | "saturated core" 판정 회색값 임계

BRIGHT_SPOT_MIN_AREA_PX | 4 | 블롭으로 칠 최소 면적(px)

MAX_TRACKED_BLOBS | 8 | 오버레이에 표시할 블롭 최대 개수

FOCUS_WIDE_RANGE_MM / _STEP_MM | 2.0 / 0.01 | wide 스캔 범위/스텝

FOCUS_NARROW_RANGE_MM / _STEP_MM | 1.0 / 0.01 | narrow 스캔 범위/스텝

FOCUS_Z_SPEED_MM_S | 0.3 | 스캔 중 Z 속도

FOCUS_MECH_SETTLE_S | 0.02 | 이동 후 기계적(진동) 정착 대기

FOCUS_EXPOSURE_MARGIN_S | 0.05 | "fresh frame" 판정에 더하는 여유시간

FOCUS_FRAME_WAIT_TIMEOUT_S | 1.0 | fresh frame 대기 타임아웃

FOCUS_BRIGHTNESS_SAMPLES | 5(2026-09-09 이전 2) | Z 스텝당 median 낼 프레임 수

FOCUS_XY_DEBOUNCE_S | 0.6 | Active 모드 재스캔 디바운스

FOCUS_PLANE_MIN/MAX_SAMPLES | 3 / 10 | 트렌드 평면 피팅 샘플 수 범위

FOCUS_PREDICT_MAX_DELTA_MM | 0.1 | 트렌드 예측이 한 번에 옮길 수 있는 최대 Z

FOCUS_PHOTO_WAIT_TIMEOUT_S | 2.0 | 초점 사진 저장 전 fresh frame 대기 타임아웃

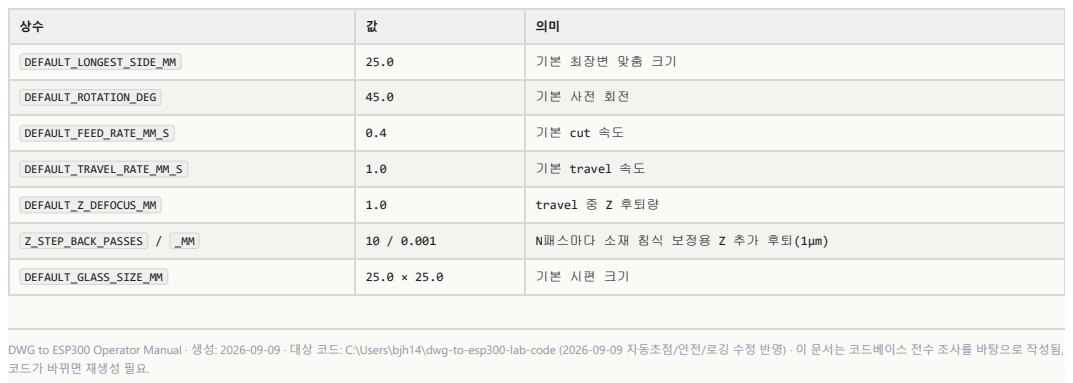
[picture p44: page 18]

DEFAULT_LONGEST_SIDE_MM | 25.0 | 기본 최장변 맞춤 크기

DEFAULT_ROTATION_DEG | 45.0 | 기본 사전 회전

DEFAULT_FEED_RATE_MM_S | 0.4 | 기본 cut 속도

DEFAULT_TRAVEL_RATE_MM_S | 1.0 | 기본 travel 속도

DEFAULT_Z_DEFOCUS_MM | 1.0 | travel 중 Z 후퇴량

Z_STEP_BACK_PASSES / _MM | 10 / 0.001 | N패스마다 소재 침식 보정용 Z 추가 후퇴(1µm)

DEFAULT_GLASS_SIZE_MM | 25.0 × 25.0 | 기본 시편 크기

DWG to ESP300 Operator Manual · 생성: 2026-09-09 · 대상 코드: C:\Users\bjh14\dwg-to-esp300-lab-code (2026-09-09 자동초점/안전/로깅 수정 반영) · 이 문서는 코드베이스 전수 조사를 바탕으로 작성됨,
코드가 바뀌면 재생성 필요.

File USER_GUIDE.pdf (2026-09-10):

### DWG to ESP300

사용 설명서

# 도면 한 장으로 레이저를 움직이는 법

### DWG to ESP300은 도면을 불러와 레이저 스테이지의 움직임 으로 바꾸고, 카메라로 초점을 맞춘 뒤, 실제 장비를 눈으로 보면서 실행까지 할 수 있는 프로그램입니다. 이 설명서 하나

면 처음부터 끝까지 따라 하실 수 있습니다.

DWG to ESP300 · User Guide | 2026-09-10

# 이 프로그램은 무엇을 하나요?

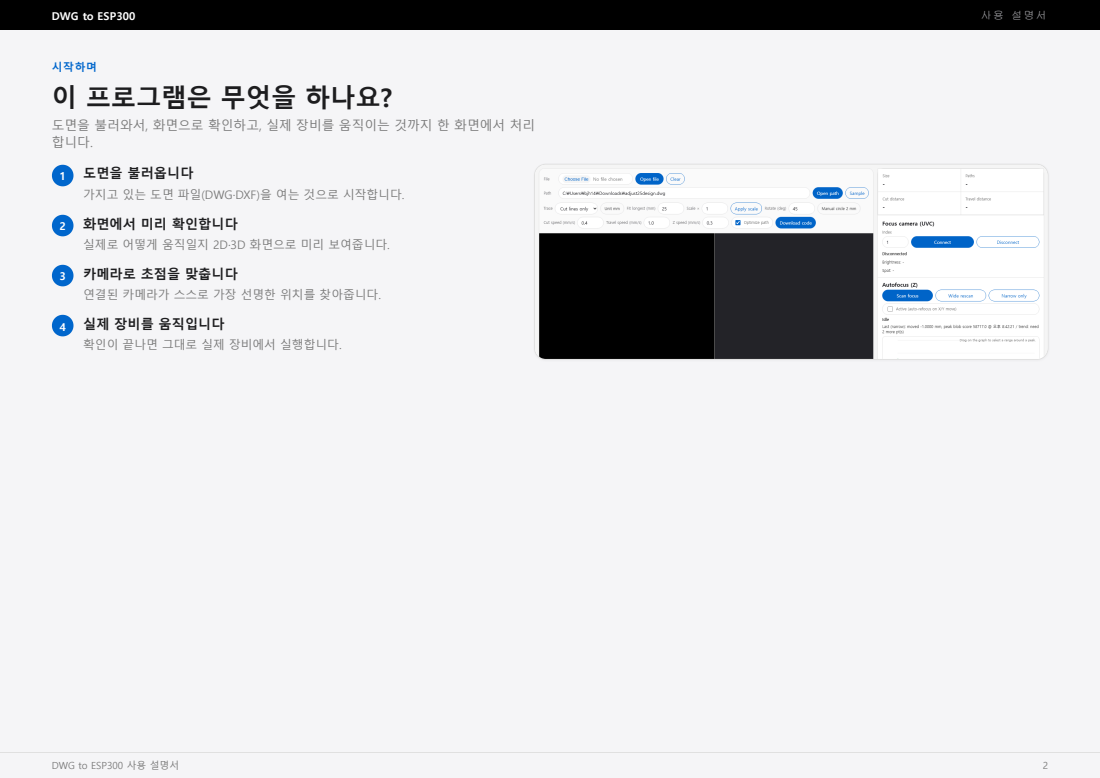
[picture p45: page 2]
DWG to ESP300; 사용 설명서; 시작하며; DWG to ESP300 사용 설명서

도면을 불러와서, 화면으로 확인하고, 실제 장비를 움직이는 것까지 한 화면에서 처리
합니다.

1 도면을 불러옵니다
가지고 있는 도면 파일(DWG·DXF)을 여는 것으로 시작합니다.
2 화면에서 미리 확인합니다
실제로 어떻게 움직일지 2D·3D 화면으로 미리 보여줍니다.
3 카메라로 초점을 맞춥니다
연결된 카메라가 스스로 가장 선명한 위치를 찾아줍니다.
4 실제 장비를 움직입니다
확인이 끝나면 그대로 실제 장비에서 실행합니다.

# 핵심 특징

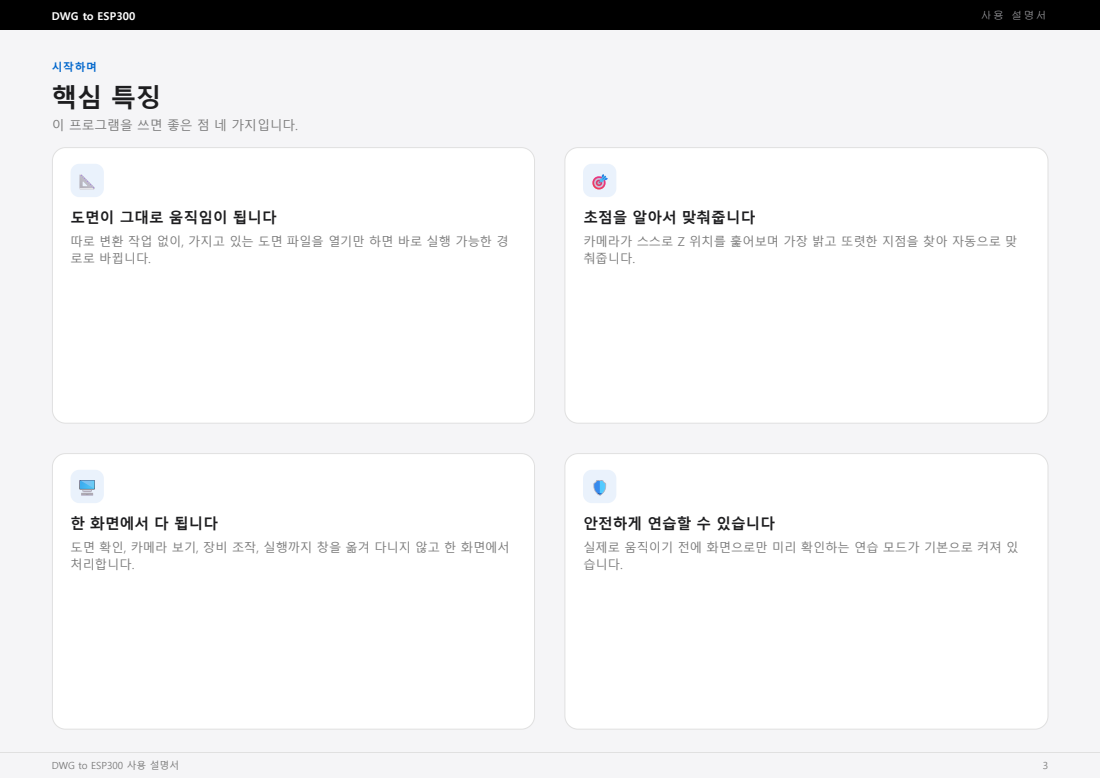
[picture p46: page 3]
시작하며

이 프로그램을 쓰면 좋은 점 네 가지입니다.

도면이 그대로 움직임이 됩니다
따로 변환 작업 없이, 가지고 있는 도면 파일을 열기만 하면 바로 실행 가능한 경
로로 바뀝니다.

초점을 알아서 맞춰줍니다
카메라가 스스로 Z 위치를 훑어보며 가장 밝고 또렷한 지점을 찾아 자동으로 맞
춰줍니다.

한 화면에서 다 됩니다
도면 확인, 카메라 보기, 장비 조작, 실행까지 창을 옮겨 다니지 않고 한 화면에서
처리합니다.

안전하게 연습할 수 있습니다
실제로 움직이기 전에 화면으로만 미리 확인하는 연습 모드가 기본으로 켜져 있
습니다.

# 시작하기 전에

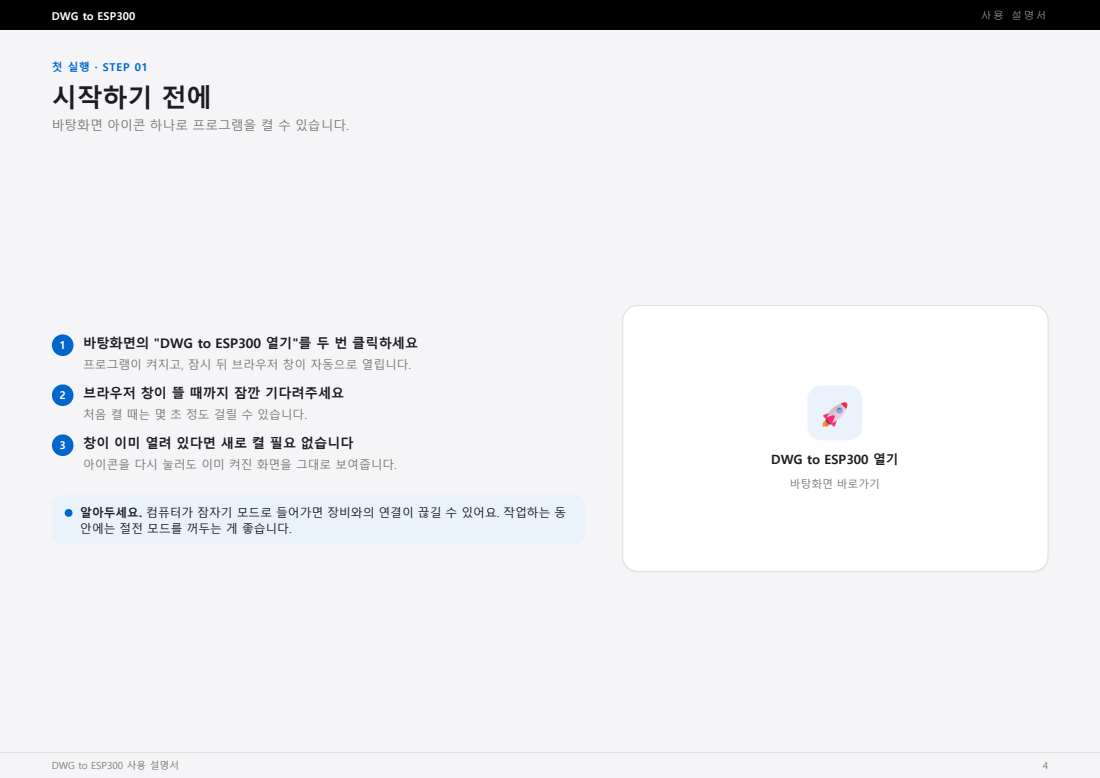
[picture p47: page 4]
첫 실행 · STEP 01; 바탕화면 바로가기

바탕화면 아이콘 하나로 프로그램을 켤 수 있습니다.

1 바탕화면의 "DWG to ESP300 열기"를 두 번 클릭하세요
프로그램이 켜지고, 잠시 뒤 브라우저 창이 자동으로 열립니다.
2 브라우저 창이 뜰 때까지 잠깐 기다려주세요
처음 켤 때는 몇 초 정도 걸릴 수 있습니다.
3 창이 이미 열려 있다면 새로 켤 필요 없습니다
아이콘을 다시 눌러도 이미 켜진 화면을 그대로 보여줍니다.

DWG to ESP300 열기

알아두세요. 컴퓨터가 잠자기 모드로 들어가면 장비와의 연결이 끊길 수 있어요. 작업하는 동
안에는 절전 모드를 꺼두는 게 좋습니다.

# 메인 화면 한눈에 보기

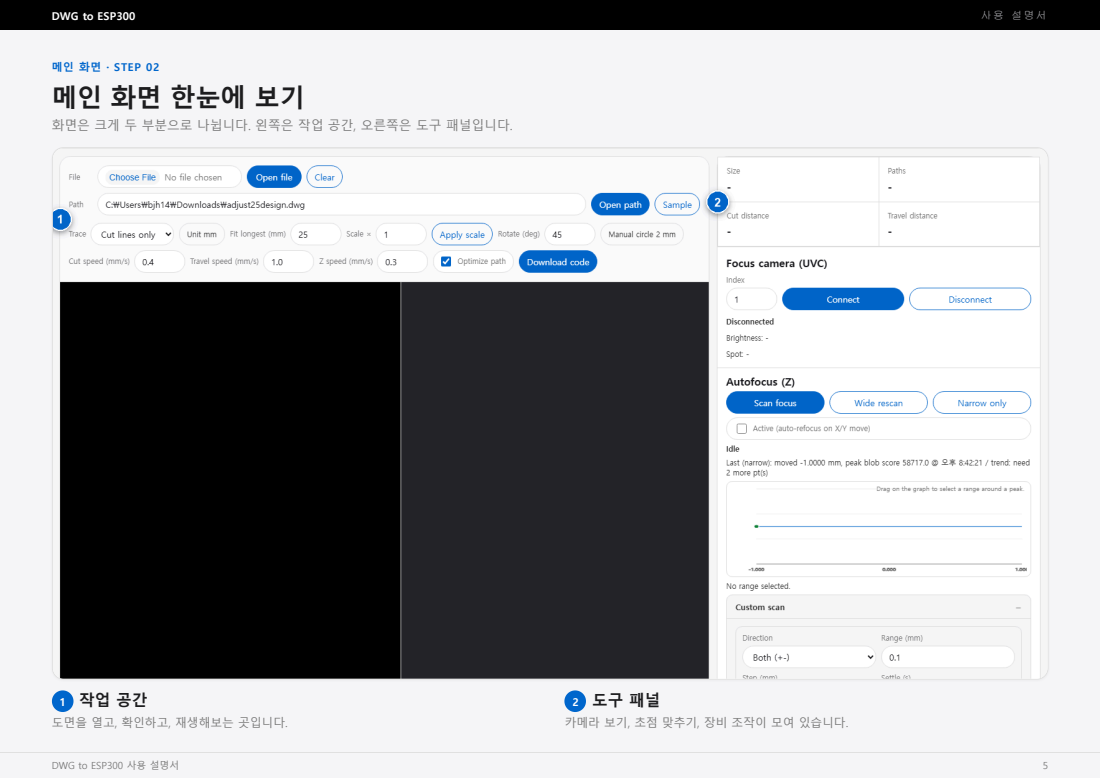
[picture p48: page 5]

메인 화면 · STEP 02

화면은 크게 두 부분으로 나뉩니다. 왼쪽은 작업 공간, 오른쪽은 도구 패널입니다.

도면을 열고, 확인하고, 재생해보는 곳입니다.

카메라 보기, 초점 맞추기, 장비 조작이 모여 있습니다.

# 도면 불러오기

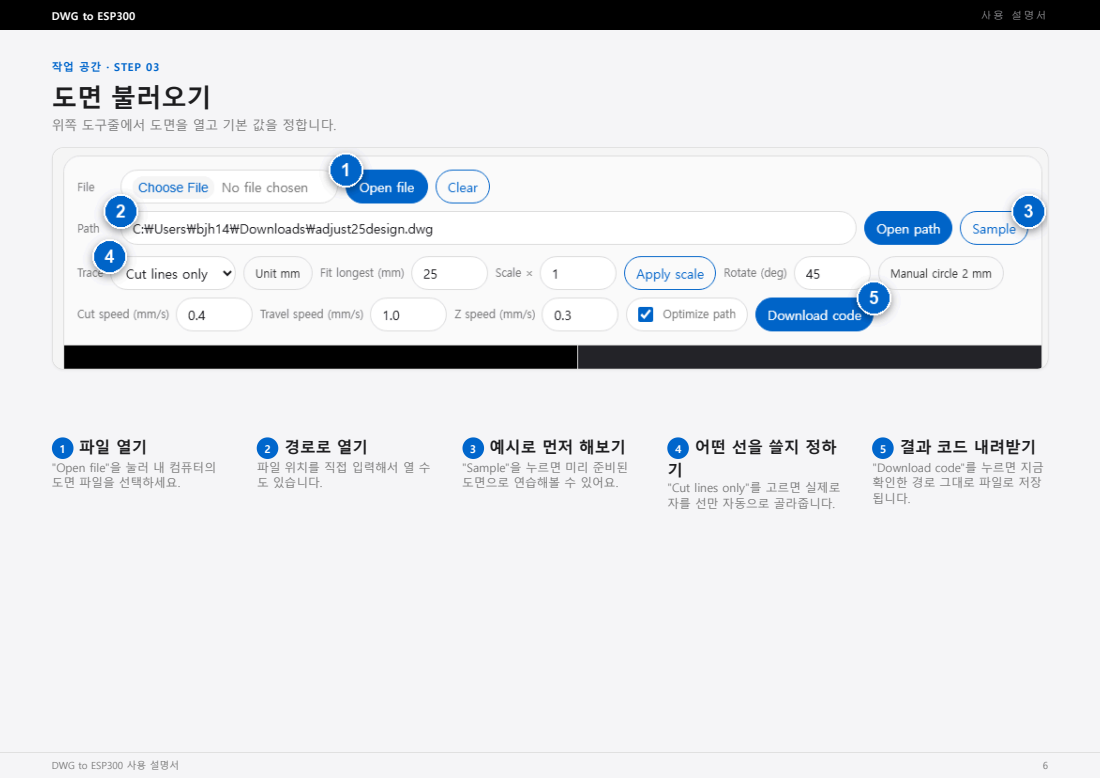
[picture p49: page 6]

작업 공간 · STEP 03

위쪽 도구줄에서 도면을 열고 기본 값을 정합니다.

"Open file"을 눌러 내 컴퓨터의
도면 파일을 선택하세요.

2 경로로 열기
파일 위치를 직접 입력해서 열 수
도 있습니다.

3 예시로 먼저 해보기
"Sample"을 누르면 미리 준비된
도면으로 연습해볼 수 있어요.

"Cut lines only"를 고르면 실제로
자를 선만 자동으로 골라줍니다.

5 결과 코드 내려받기
"Download code"를 누르면 지금
확인한 경로 그대로 파일로 저장
됩니다.

# 미리보기에서 확인하기

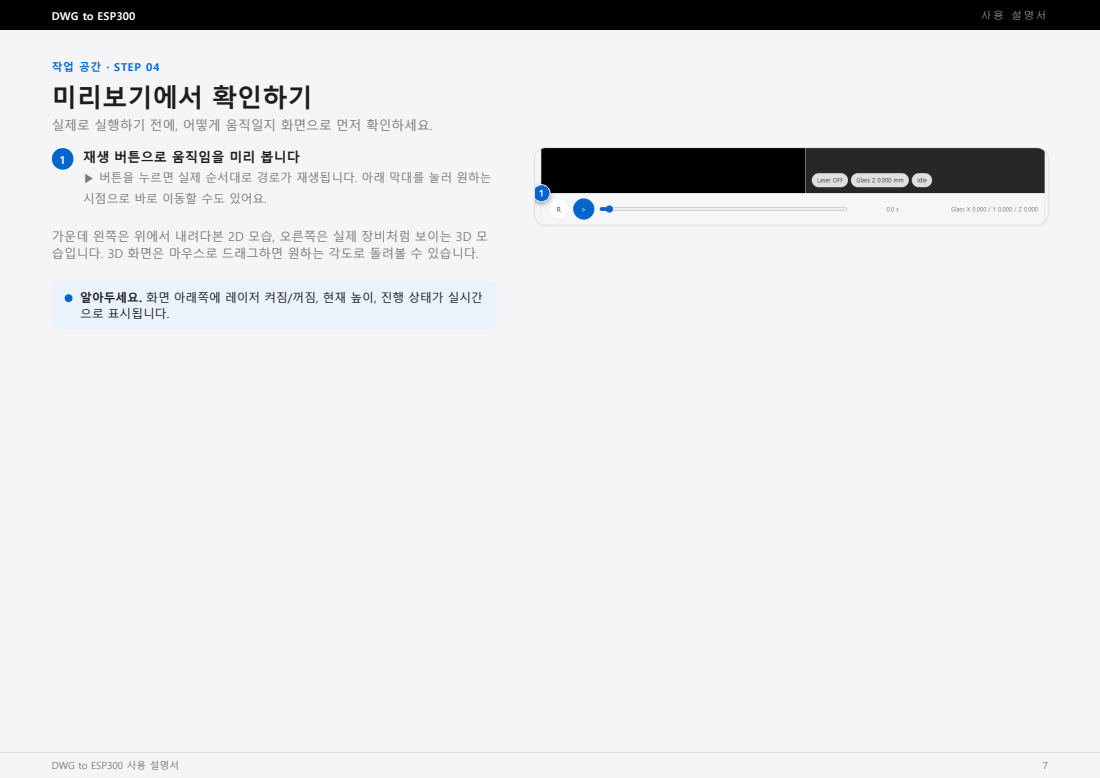
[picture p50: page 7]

작업 공간 · STEP 04

실제로 실행하기 전에, 어떻게 움직일지 화면으로 먼저 확인하세요.

1 재생 버튼으로 움직임을 미리 봅니다
▶ 버튼을 누르면 실제 순서대로 경로가 재생됩니다. 아래 막대를 눌러 원하는
시점으로 바로 이동할 수도 있어요.

가운데 왼쪽은 위에서 내려다본 2D 모습, 오른쪽은 실제 장비처럼 보이는 3D 모
습입니다. 3D 화면은 마우스로 드래그하면 원하는 각도로 돌려볼 수 있습니다.

알아두세요. 화면 아래쪽에 레이저 켜짐/꺼짐, 현재 높이, 진행 상태가 실시간
으로 표시됩니다.

# 카메라로 실시간으로 보기


도구 패널 · STEP 05

연결된 카메라 영상을 여기서 바로 확인할 수 있습니다.

1 Focus camera
카메라 화면이 나오는 자리입니다.
연결할 카메라 번호입니다. 카메라가 하나뿐이면 기본값 그대로 두세요.
3 Connect
눌러서 카메라를 연결하세요. 연결되면 실시간 영상이 나타납니다.
화면을 클릭하면 그 위치를 기준점으로 지정할 수 있습니다.

# 자동으로 초점 맞추기


도구 패널 · STEP 06

버튼 하나로 가장 선명한 높이를 찾아줍니다.

1 Scan focus
가장 기본적인 초점 찾기입니다. 처음 켠 뒤엔 이 버튼을 눌러주세요.
2 Wide rescan
넓은 범위를 다시 살펴봅니다. 초점이 많이 벗어난 것 같을 때 사용하세요.
3 Narrow only
좁은 범위만 빠르게 다시 확인합니다.
4 Active
켜두면 위치를 옮길 때마다 자동으로 초점을 다시 맞춰줍니다.
5 그래프
어느 높이에서 가장 밝았는지 보여줍니다. 드래그하면 그 구간만 다시 확인할
수 있어요.

# 초점을 더 세밀하게 맞추기


도구 패널 · STEP 07

기본 자동초점으로 충분하지 않을 때 펼쳐서 쓰는 기능입니다. 눌러서 펼치고 접을 수
있어요.

1 Custom scan
범위와 간격을 직접 정해서 원하는 구간만 자세히 훑어봅니다.
2 Timing check
지금 설정이 충분히 정확한지 확인해보는 자가 점검 기능입니다.
3 Spiral survey
여러 지점을 돌면서 각 위치마다 초점을 확인하고 지도를 만들어줍니다.

주의하세요. 여러 지점을 도는 동안에는 화면을 계속 지켜봐 주세요. 이상하
다 싶으면 언제든 Space 키를 눌러 바로 멈출 수 있습니다.

# 장비 연결하기


도구 패널 · STEP 08

실제 장비를 움직이려면 먼저 연결부터 해야 합니다.

1 Jog 탭
장비를 직접 조작하는 화면입니다. 기본으로 열려 있어요.
2 Shapes 탭
도면 없이 직접 도형을 그리는 화면입니다.
3 Paths 탭
불러온 경로들을 하나씩 관리하는 화면입니다.
4 Port
장비와 연결된 통신 포트입니다. 특별한 안내가 없다면 기본값 그대로 두세요.
장비가 움직일 수 있는 최대 범위입니다. 이 범위를 벗어나려고 하면 안전을 위
해 자동으로 멈춥니다.
6 Dry run(연습 모드)
체크되어 있으면 실제로는 움직이지 않고 화면으로만 보여줍니다. 실제로 움직
이려면 이 체크를 해제하세요.
7 Connect
눌러서 장비와 연결하세요.

# 손으로 움직여보기


도구 패널 · STEP 09

연결이 끝났다면, 화살표 버튼으로 장비를 직접 움직여볼 수 있습니다.

1 한 번에 움직이는 거리
버튼을 누를 때마다 얼마나 움직일지 고르세요. 작은 값일수록 아주 조금씩 움
직입니다.
누르고 있는 동안 그 방향으로 계속 움직입니다. 키보드 방향키로도 조작할 수
있어요.
가운데 빨간 STOP 버튼입니다. 누르면 바로 멈추고, 다시 움직이려면 처음부터
연결을 다시 해야 합니다. 키보드 Space 키도 똑같이 동작해요.
Z focus 버튼으로 위아래(초점) 높이를 조금씩 조정합니다.

주의하세요. 비상 정지는 언제 눌러도 안전합니다. 확인 없이 바로 멈추도록
만들어졌어요.

# 기준 위치 정하고 실행하기


도구 패널 · STEP 10

자주 쓰는 위치를 저장해두고, 준비가 끝나면 실제로 실행합니다.

1 Home
장비의 원래 기준점(0,0,0)으로 이동합니다. 크게 움직일 수 있어 한 번 더 확인
을 물어봅니다.
2 Set local home
지금 위치를 나만의 기준점으로 저장합니다. 실제 장비는 움직이지 않아요.
3 Go to local home
저장해둔 나만의 기준점으로 돌아갑니다.
4 좌표로 이동
원하는 위치(X/Y/Z)를 직접 입력하고 "Go"를 누르세요.
5 Run on machine
지금까지 확인한 경로를 실제 장비에서 실행합니다. 실행 전 한 번 더 확인을
물어봅니다.
6 Stop run
실행 중인 작업을 멈춥니다.

# 도면 없이 도형 직접 그리기


도구 패널 · STEP 11

도면 파일이 없어도, 원하는 모양을 직접 만들 수 있습니다.

1 도형 종류 고르기
선, 사각형, 원, 나선 중에서 고르세요.
2 크기와 위치 입력
고른 도형에 맞는 값을 숫자로 입력합니다.
3 Blank
지금까지 그린 도형을 모두 지우고 새로 시작합니다.
4 Add shape
입력한 값 그대로 도형 하나를 추가합니다.
5 Delete selected
Paths 탭에서 선택해둔 도형을 지웁니다.

# 경로 선택하고 관리하기


도구 패널 · STEP 12

불러온 경로가 여러 개라면, 원하는 것만 골라 쓸 수 있습니다.

1 All
모든 경로를 한 번에 선택합니다.
2 None
선택을 모두 해제합니다.
같은 자리를 몇 번 반복해서 지나갈지 정합니다.
4 Apply
지금 선택한 경로 전체에 반복 횟수를 한 번에 적용합니다.

이 아래로 경로가 하나씩 목록으로 나오고, 개별로도 체크하거나 반복 횟수를 바꿀
수 있습니다.

설정 · STEP 13

# 설정값 살펴보기

따로 "설정" 화면은 없고, 각 기능 옆에 바로 숫자를 입력하는 방식입니다. 자주 보게
될 값들을 정리했습니다.
이름 | 어디 있나요 | 무엇을 정하나요 | 기본값
Cut speed | 도면 불러오기 화면 | 실제로 자르며 움직이는 빠르기 | 0.4mm/s
Travel speed | 도면 불러오기 화면 | 자르지 않고 이동만 할 때의 빠르기 | 1.0mm/s
Z speed | 도면 불러오기 화면 | 초점 높이를 바꿀 때의 빠르기 | 0.3mm/s
이동 범위(X-Y) | 장비 연결 화면 | 장비가 좌우/앞뒤로 움직일 수 있는 최대 범위 | 75mm
이동 범위(Z) | 장비 연결 화면 | 장비가 위아래로 움직일 수 있는 최대 범위 | 20mm
한 번에 움직이는 거리 | 손으로 움직이기 화면 | 버튼 한 번 누를 때 움직이는 양 | 0.1mm

알아두세요. 이동 범위는 안전을 위한 값입니다. 특별한 이유 없이는 기본값을 그대로 쓰는 것을 권장합니다.

# 가장 많이 쓰는 흐름

미리보기; 연결하기; 초점 맞추기; 실행하기

자주 사용하는 기능

매번 이 다섯 단계만 기억하면 됩니다.

Toolbar에서 도면을 불러옵

재생 버튼으로 움직임을 확
인합니다.

카메라와 장비를 연결합니

Scan focus로 자동으로 맞
춥니다.

Run on machine으로 실제
작업합니다.

# 더 편하게 쓰는 방법

알아두면 좋은 팁

1 Active를 켜두면 편해요
자리를 옮길 때마다 자동으로 초점을 다시 맞춰줘서 매번 누를 필요가 없어요.

2 처음엔 연습 모드로
Dry run을 켜둔 채로 먼저 흐름을 익히고, 익숙해지면 꺼서 실제로 움직여보세요.

3 키보드가 더 빠를 때도 있어요
방향키로 이동, Page Up/Down으로 높이 조정, Space로 즉시 정지할 수 있습니다.

4 Sample로 먼저 연습하기
내 도면이 준비되지 않았다면 예시 도면으로 먼저 전체 흐름을 익혀보세요.

5 작업 중엔 컴퓨터를 재우지 마세요
절전 모드로 들어가면 연결이 끊어질 수 있어요.

6 이상하면 일단 멈추기
확신이 없을 땐 STOP(비상 정지)부터 누르고 상황을 확인하세요. 되돌리지 못할 걱정
은 없습니다.

문제 해결

# 이럴 땐 이렇게 하세요

Q. 카메라 화면에 아무것도 안 보여요; 러 연결부터 해주세요.

카메라가 아직 연결되지 않았을 수 있어요. Focus camera 패널에서 Connect를 눌

Q. 장비가 움직이지 않아요; 시 연결해보세요.

Dry run(연습 모드)이 켜져 있으면 실제로는 움직이지 않아요. 체크를 해제하고 다

Q. "이동 범위를 벗어났다"는 안내가 떠요; 한다면 이동 범위 값을 늘린 뒤 다시 연결하세요.

안전을 위해 정해둔 이동 범위를 벗어나려고 했다는 뜻이에요. 정말 그 위치로 가야

Q. 비상 정지를 눌렀어요, 이제 뭘 하나요; 눌러 연결하면 이어서 쓸 수 있어요.

STOP을 누르면 안전을 위해 연결이 끊어집니다. 상황을 확인한 뒤 Connect를 다시

Q. 초점 찾기가 너무 오래 걸려요; 카메라를 다시 연결해보세요.

카메라 연결에 문제가 있을 수 있어요. 화면을 지켜보다가 이상하면 STOP을 누르고

Q. 실행 중 갑자기 멈췄어요; 하고 실행해보세요.

장비와의 연결 상태를 확인해주세요. 케이블이나 USB 연결을 점검한 뒤 다시 연결

마무리

# 이제 준비가 끝났습니다

도면 열기부터 카메라로 초점 맞추기, 그리고 실제 장비 실행까지 — 이 설명서에 나온 순서대로 따라 하면 됩니다. 막히는 부분이 있다면 언제든 이 설명서의 해당 페이지를 다시 펼쳐보세요.

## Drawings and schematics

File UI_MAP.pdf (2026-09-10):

U I E X P L A N A T I O N M A P

# DWG to ESP300

# 화면 구석구석 설명맵

## 실제 화면을 그대로 캡처해서 번호 핀을 붙이고, 왼쪽에 그 번호 가 뭘 하는 컨트롤인지 설명. 스크린샷은 브라우저에서 직접 캡

처한 실제 화면이지 그림이 아닙니다.

DWG to ESP300 — UI Explanation Map | 전체 10개 화면 구역

00 · 시 작 하 기 전 에

# 이 설명맵을 읽는 법

## 오른쪽 큰 영역은 실제로 돌아가는 앱을 브라우저에서 그대로 캡처한 화면입니다. 그

림이 아닙니다. 화면 위 빨간 동그라미 번호가 왼쪽 설명 목록의 번호와 짝을 이룹니다.

### 1 오른쪽은 실제 화면

서버(port 8768)를 켠 채로 Playwright로 직접 캡처했습니다. 숫자·상태 텍스트도 그
순간 실제 값입니다.

### 2 번호 핀 = 왼쪽 설명

빨간 원 번호는 그 자리의 컨트롤을 가리킵니다. 왼쪽 목록에서 같은 번호를 찾으면 설명이 있습니다.

### 3 이 문서는 "어디에 뭐가 있나"만

API 필드, 내부 동작, 안전장치의 자세한 원리는 짝문서 MANUAL.pdf 를 참고하세요.

### 4 초록 상자 = 팁, 노란 상자 = 주의

몰라도 되지만 알면 편한 것과, 놓치면 곤란한 것을 구분해뒀습니다.

화면 상태 안내
지금 캡처는 하드웨어 미연결(Dry run) 상태 + 이전 세션에서 남은 실측값(밝기 그래프, survey 진행 1/5점 등)이 그대로 보입니다. 실제 rig의 진짜 데이터입니다 — 가짜로 채운 예시가 아닙니다.

00 · 시 작 하 기 전 에
목차

### 01 Toolbar — 도면 열기 & 트레이스 설정

### 02 미리보기 하단 상태바 & 타임라인

## 03 지표 타일 & Focus Camera 패널

### 04 Autofocus 스캔 컨트롤 & 그래프

## 05 Custom scan / Timing check / Spiral survey

### 06 탭 전환 & Jog 연결 필드

## 07 조그 패드 & Z focus

## 08 Home / 로컬홈 / Go-to & Run on machine

## 09 Shapes 탭

## 10 Paths 탭

# 도면 열기 & 트레이스 설정

## 줄. 1 Open file

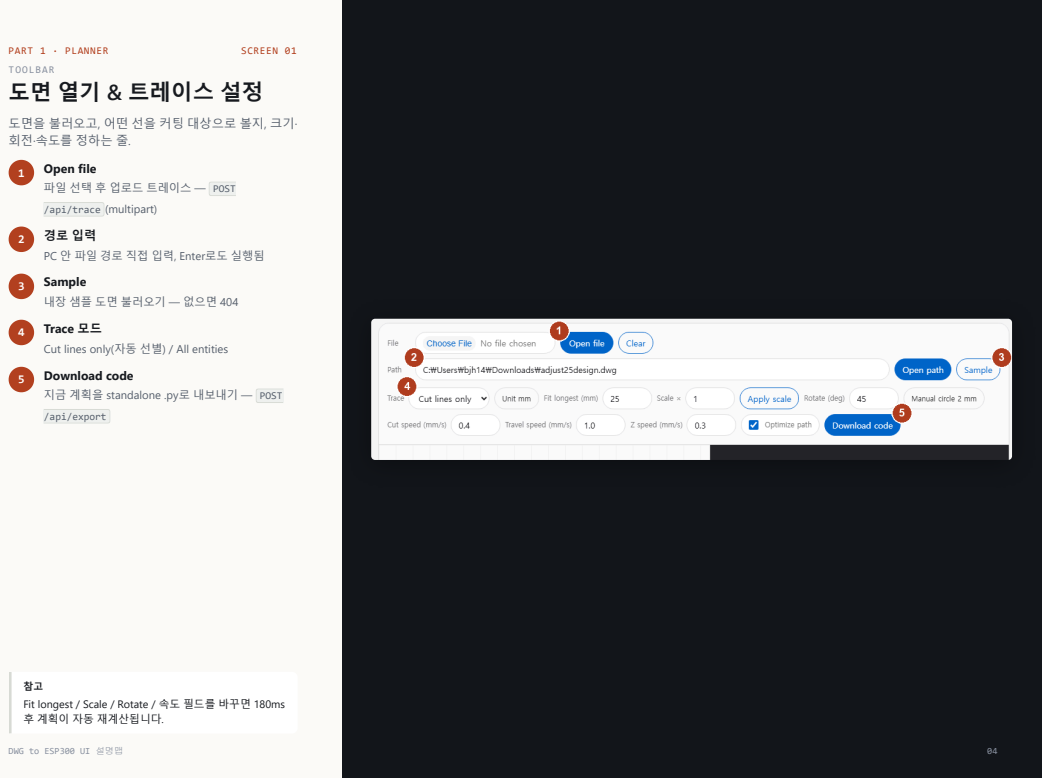
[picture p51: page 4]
(multipart); 로 내보내기 —; DWG to ESP300 UI 설명맵

도면을 불러오고, 어떤 선을 커팅 대상으로 볼지, 크기·
회전·속도를 정하는

후 업로드 트레이스 —
3 Sample
내장 샘플 도면 불러오기 — 없으면 404
Trace 모드
Cut lines only(자동 선별) / All entities
5 Download code
지금 계획을 standalone .py

안 파일 경로 직접 입력, Enter로도 실행됨

Fit longest / Scale / Rotate / 속도 필드를 바꾸면 180ms 후 계획이 자동 재계산됩니다.

PART 1 · PLANNER | SCREEN 02
PREVIEW 하단

# 상태바 & 재생 타임라인

가운데 큰 검은 영역이 2D/3D 미리보기입니다(도면이 없으면 비어있음). 그 아래 줄이 현재 상태와 재생 컨 트롤.

### 1 재생 트랜스포트

R(리셋) / ▶(재생) / 스크럽바 — 계획된 경로를 시 간순으로 미리 재생. requestAnimationFrame 기 반, 타이머 아님

### 배지 3개(Laser OFF / Glass Z / Idle)는 재생 중 현재 레이

저 on/off, Z 높이, 실행 상태를 보여줍니다. 우측엔 재생 경과 Glass X/Y/Z 좌표.

참고
"Default sample DWG not found" 같은 안내문도 이 줄
에 뜹니다 — 에러가 아니라 다음에 뭘 해야 하는지 알 려주는 상태 메시지.

# 지표 타일 & Focus Camera

C

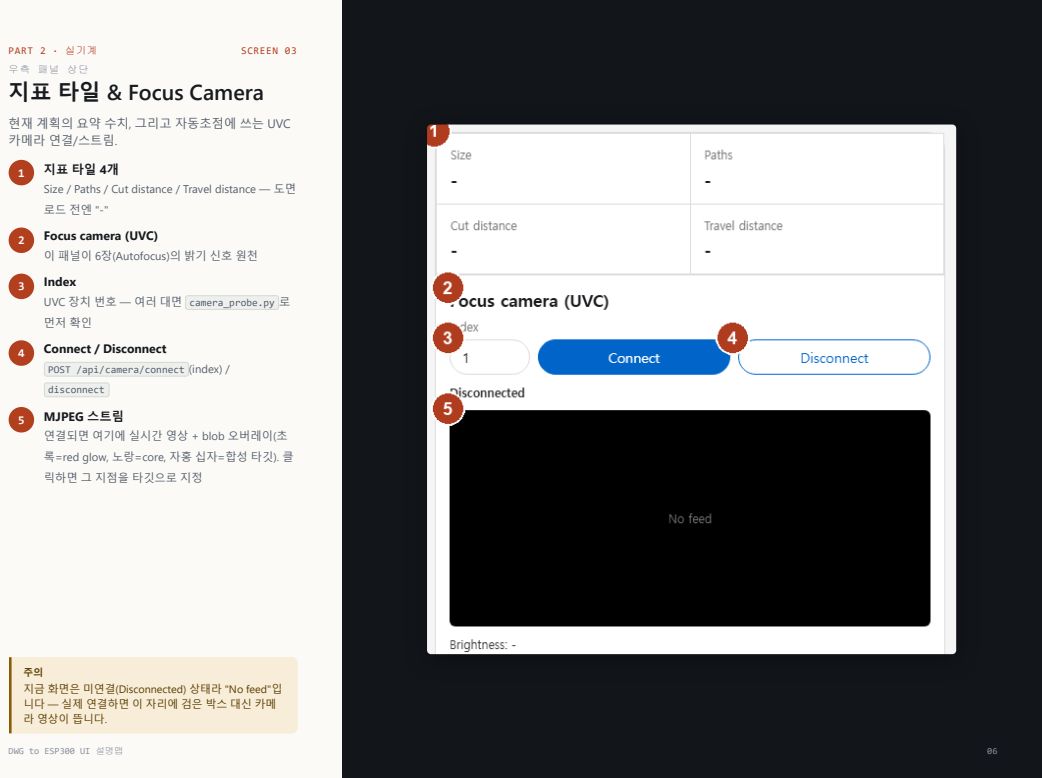
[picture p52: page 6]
/스트림. 1; t (index) /

현재 계획의 요약 수치, 그리고 자동초점에 쓰는 UV
카메라 연결

Size / Paths / Cut distance / Travel distance — 도면
Focus camera (UVC) 이 패널이 6장(Autofocus)

Index
UVC 장치 번호 — 여러 대면

4 Connect / Disconnect POST /api/camera/conn

5 MJPEG 스트림
연결되면 여기에 실시간 영상 + blob 오버레이
록=red glow, 노랑=core, 자홍 십자
릭하면

그 지점을 타깃으로 지정

지금 화면은 미연결(Disconnected) 상태라 "No feed"
니다 — 실제 연결하면
라 영상이 뜹니다.

이 자리에 검은 박스 대신 카메

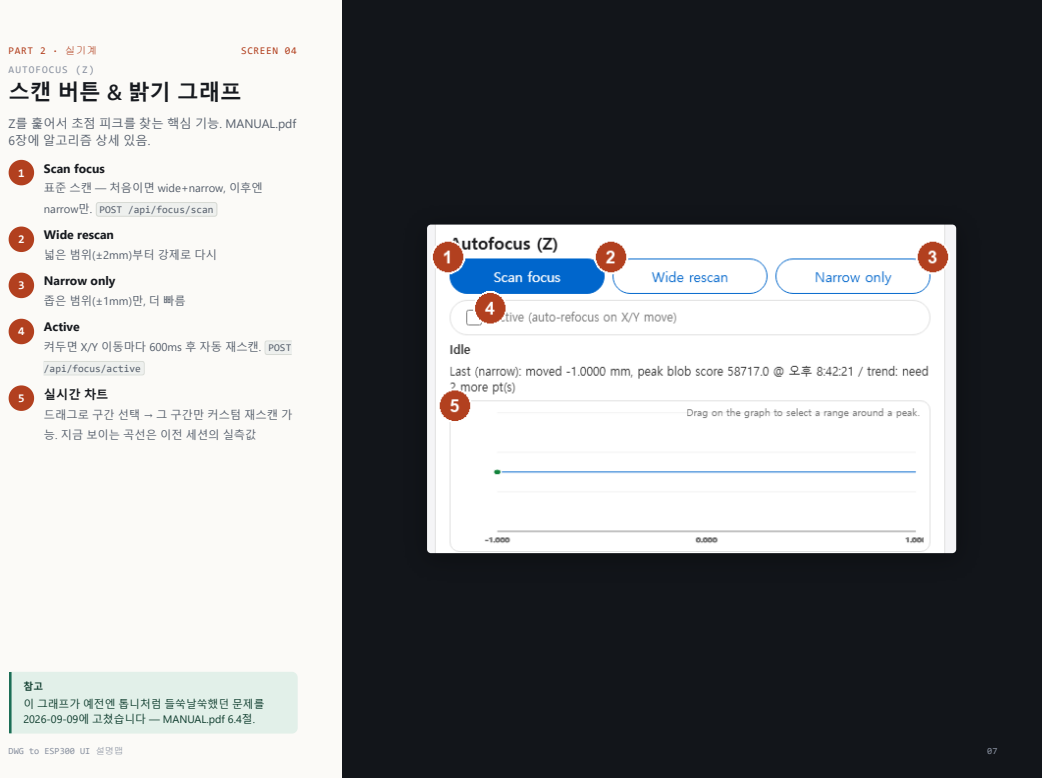
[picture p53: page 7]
스캔 버튼 & 밝기 그래프 Z를 훑어서 초점 피크를 찾는 핵심 기능. MANUAL.pdf 6장에 알고리즘 상세 있음. 1; Scan focus; 후 자동 재스캔.

표준 스캔 — 처음이면 wide+narrow, 이후엔
narrow
2 Wide rescan
넓은 범위(±2mm)부터 강제로 다시
3 Narrow only
4 Activ
켜두면 X/Y 이동마다 600ms

5 실시간 차트
드래그로 구간 선택 →
능. 지금 보이는 곡선은 이전 세션의 실측값

그 구간만 커스텀 재스캔

이 그래프가 예전엔 톱니처럼 들쑥날쑥했던 문제를

에 고쳤습니다 — MANUAL.pdf 6.4

# Custom scan / Timing check / Spiral sur

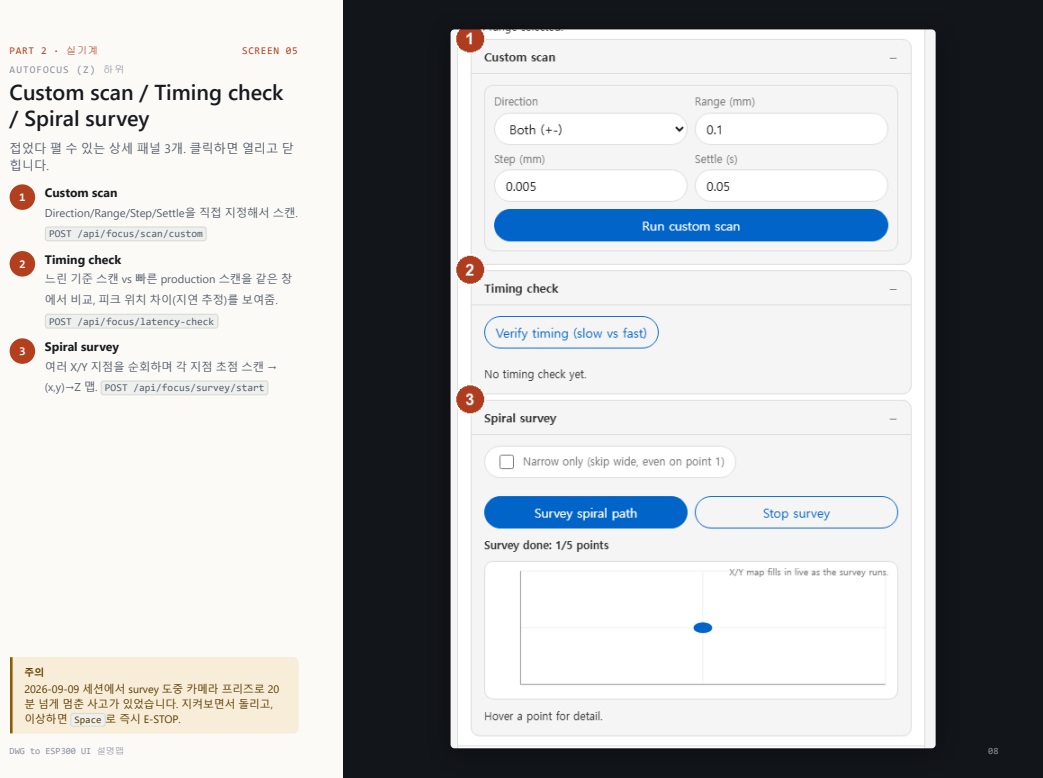
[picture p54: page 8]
위 vey; 접었다; 개. 클릭하면 열리고; 힙니다. 1; Custom scan; vey; 이상하면; 로 즉시 E-STOP.

Direction/Range/Step/Settle

을 직접 지정해서 스캔. POST /api/focus/scan/custom

2 Timing check
느린 기준 스캔 vs 빠른 production 스캔을 같은

를 보여줌. POST /api/focus/latency-check

3 Spiral sur
여러 X/Y 지점을 순회하며

2026-09-09 세션에서 survey 도중 카메라 프리즈로 20 분 넘게 멈춘 사고가 있었습니다. 지켜보면서 돌리고,

# 탭 전환 & ESP300 연결

## 맨 아래는 Jog/Shapes/Paths 3

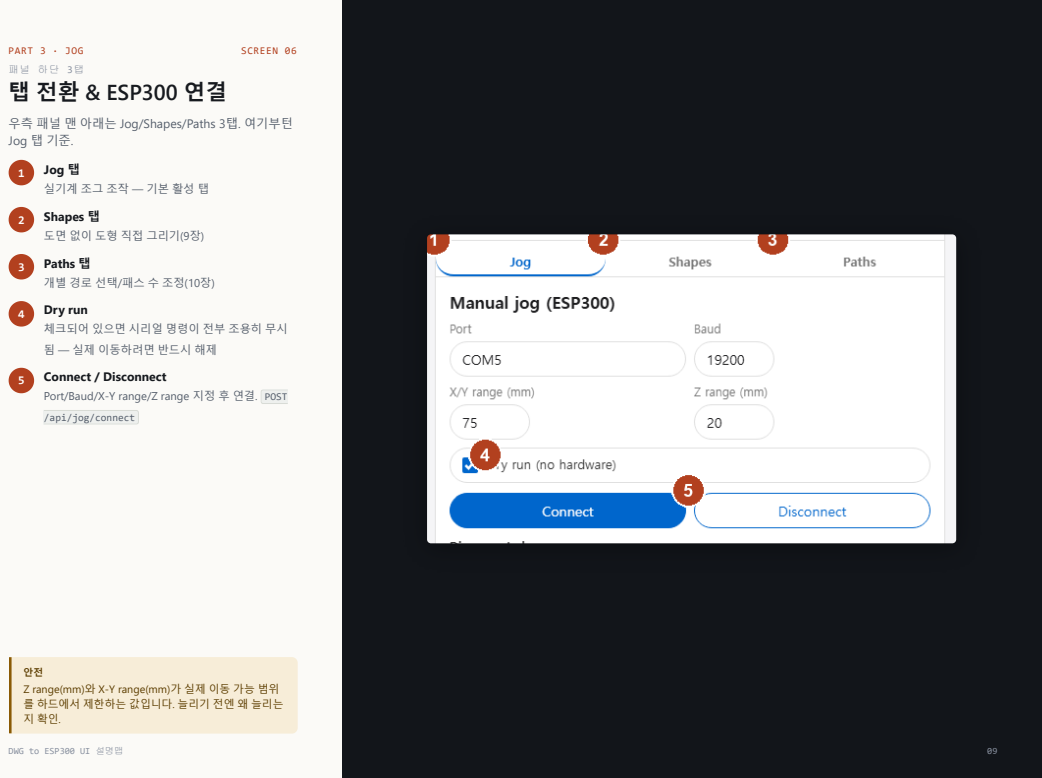
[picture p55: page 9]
탭. 여기부턴; Jog; Jog 탭; 와 X-Y range(mm); 왜 늘리는

실기계 조그 조작 — 기본 활성
2 Shapes
도면 없이 도형 직접 그리기(9
Paths

4 Dry run
체크되어 있으면 시리얼 명령이 전부 조용히 무시 됨 — 실제 이동하려면 반드시 해제

5 Connect / Disconnect Port/Baud/X-Y range/Z range 지정

Z range(mm)
를 하드에서 제한하는 값입니다. 늘리기 전엔

## tep(mm)

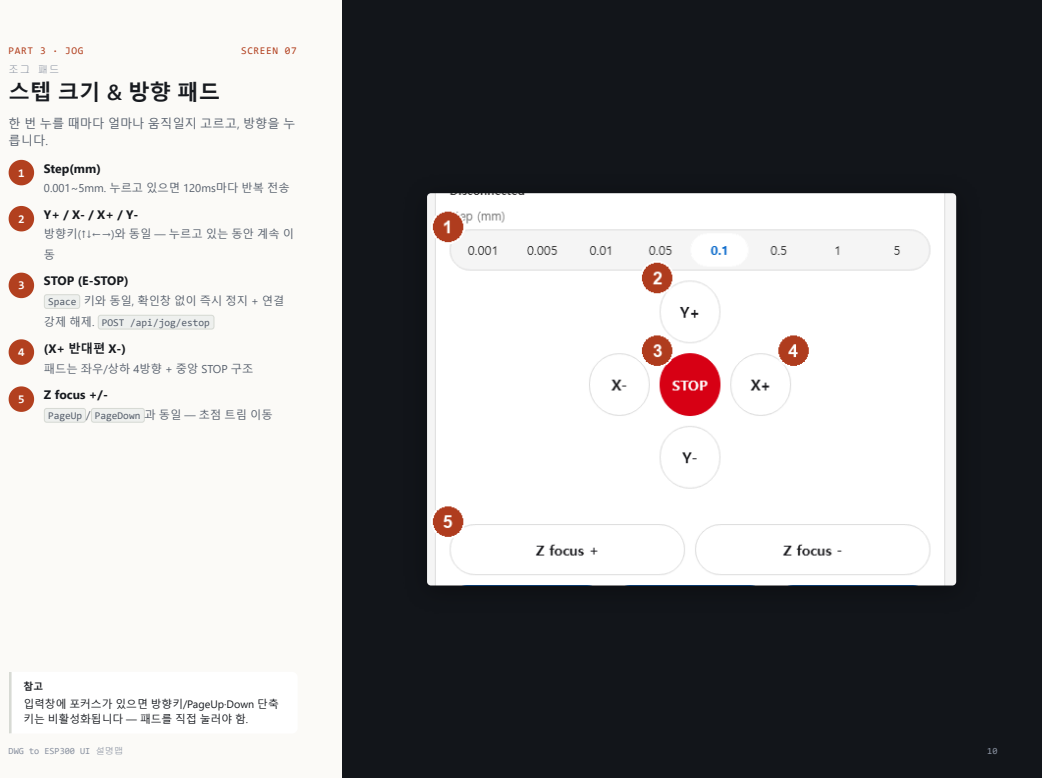
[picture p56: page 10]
릅니다. 1

스텝 크기 & 방향 패드 한 번 누를 때마다 얼마나 움직일지 고르고, 방향을

0.001~5mm. 누르고 있으면 120ms마다 반복 전송
방향키(↑↓←→)와 동일 — 누르고 있는 동안 계속
3 STOP (E-STOP) Space 키와 동일, 확인창 없이 즉시 정지 + 연결

4 (X+ 반대편 X-)
패드는 좌우
5 Z focus +/- PageUp / Pag

/상하 4방향 + 중앙 STOP 구조

입력창에 포커스가 있으면 방향키/PageUp·Down 단축
키는 비활성화됩니다 — 패드를 직접 눌러야

# Home / Go-to & Run on machine

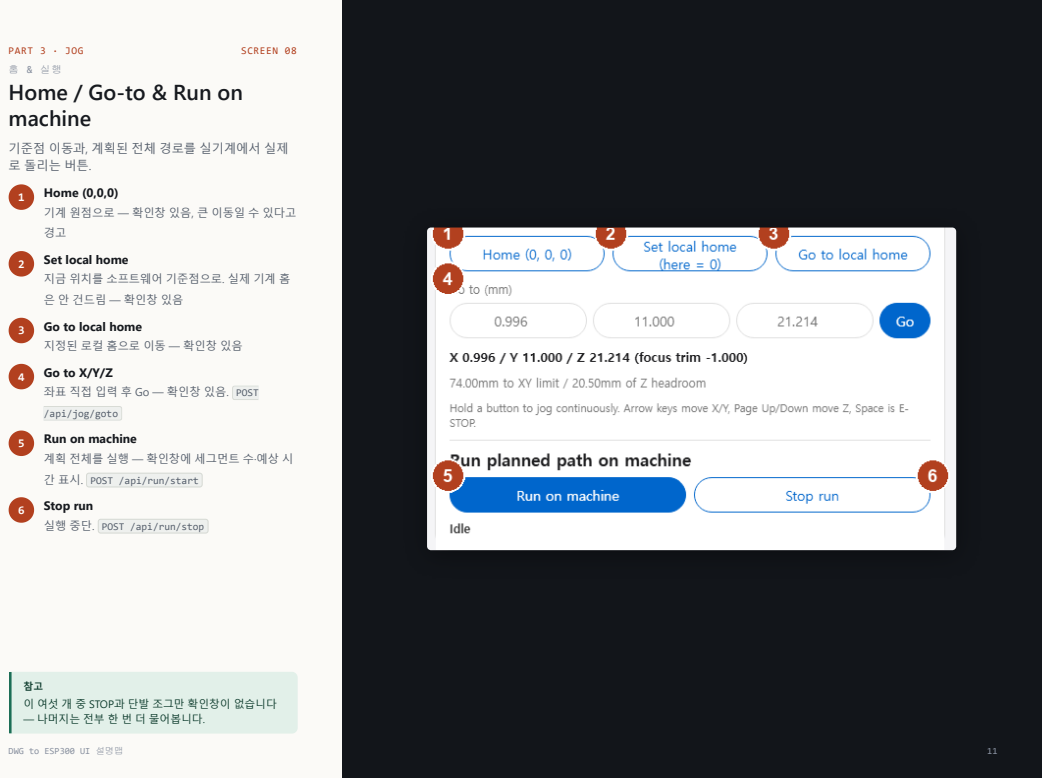
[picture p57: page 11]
기준점 이동과, 계획된 전체 경로를 실기계에서 실제 로 돌리는 버튼. 1; Home (0,0,0); 큰 이동일; 수 있다고; top run; 중 STOP — 나머지는 전부

기계 원점으로 — 확인창 있음,
2 Set local home
지금 위치를 소프트웨어 기준점으로. 실제 기계
안 건드림 — 확인창 있음
3 Go to local home
지정된 로컬 홈으로 이동 — 확인창 있음
5 Run on machine
계획 전체를 실행 — 확인창에 세그먼트

후 Go — 확인창 있음.

과 단발 조그만 확인창이 없습니다
더 물어봅니다.

## 도형 직접 추가 DWG 없이 Line/Rect/Circle/Spiral

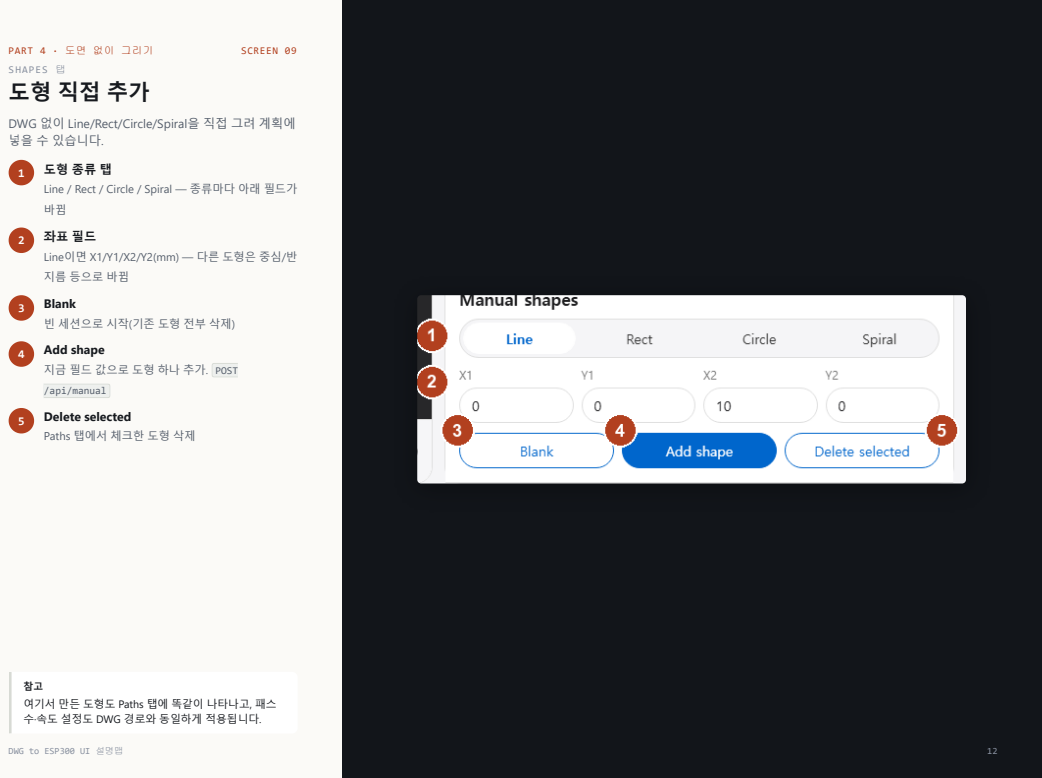
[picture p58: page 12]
수 있습니다. 1

을 직접 그려 계획에

Line / Rect / Circle / Spiral — 종류마다 아래 필드가
Line이면 X1/Y1/X2/Y2(mm) — 다른 도형은 중심
지름 등으로 바뀜
3 Blank 빈 세션으로 시작

4 Add shape
지금 필드 값으로 도형 하나 추가.
5 Delete selected Paths 탭에서 체크한 도형 삭제 참고

여기서 만든 도형도 Paths 탭에 똑같이 나타나고, 패스 수·속도 설정도 DWG 경로와 동일하게 적용됩니다.
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

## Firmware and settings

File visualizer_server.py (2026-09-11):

from __future__ import annotations

import argparse
import cgi
import csv
import importlib.util
import json
import math
import mimetypes
import re
import shutil
import statistics
import threading
import time
import uuid
from dataclasses import asdict
from datetime import datetime, timezone
from http.server import BaseHTTPRequestHandler, ThreadingHTTPServer
from pathlib import Path
from urllib.parse import parse_qs, quote, urlparse

import cv2
import numpy as np
import serial

import focus_autocal

# MSMF backend spams a C++ warning on every failed grabFrame (e.g. camera
# unplugged) with no Python-side rate limit -- left running overnight this
# fills a log file at ~25 lines/sec. Silence it; failures are still handled
# in CameraController._capture_loop below.
cv2.utils.logging.setLogLevel(cv2.utils.logging.LOG_LEVEL_SILENT)

from dwg_to_esp300 import (
    LaserPath,
    apply_fit_scale,
    cap_scale_to_circle,
    decode_dxf_unicode_escapes,
    distance,
    ensure_dxf,
    extract_paths,
    generate_esp300_script,
    orient_path_from_current,
    raw_bbox,
    rotate_paths,
    select_design_paths,
    transform_paths,
    write_preview_svg,
)


ROOT = Path(__file__).resolve().parent
STATIC_ROOT = ROOT / "visualizer"
UPLOAD_ROOT = ROOT / "uploads"
GENERATED_ROOT = ROOT / "generated"
DEFAULT_SOURCE = Path(r"C:\Users\bjh14\Downloads\adjust25design.dwg")
DEFAULT_LONGEST_SIDE_MM = 25.0
DEFAULT_ROTATION_DEG = 45.0
FIXED_REFERENCE_CIRCLE_DIAMETER_MM = 2.0
DEFAULT_FEED_RATE_MM_S = 0.4
DEFAULT_TRAVEL_RATE_MM_S = 1.0
DEFAULT_FOCUS_Z_MM = 0.0
DEFAULT_Z_DEFOCUS_MM = 1.0
DEFAULT_Z_SPEED_MM_S = 0.3
Z_STEP_BACK_PASSES = 10
Z_STEP_BACK_MM = 0.001
DEFAULT_COMMAND_SETTLE_S = 0.05
DEFAULT_POSITION_TOLERANCE_MM = 0.003
DEFAULT_GLASS_SIZE_MM = (25.0, 25.0)
DEFAULT_USABLE_MARGIN_MM = 0.05
CURVE_FLATTENING_SCALE_HINT = 25.4
SCRIPT_CHOICES = {
    "full": ROOT / "adjust25design_esp300.py",
    "outline": ROOT / "adjust25design_outline_esp300.py",
}

SESSIONS: dict[str, dict] = {}

JOG_AXES = {"x": 1, "y": 2, "z": 3}
JOG_DEFAULT_BAUDRATE = 19200
JOG_MOTOR_SETTLE_S = 0.05
JOG_TP_RETRIES = 5
JOG_TP_RETRY_DELAY = 0.08
JOG_Z_RANGE_MM = 10.0
JOG_STEP_MAX_MM = 5.0
JOG_SPEED_MAX_MM_S = 10.0
JOG_HOME_SPEED_MM_S = 5.0
JOG_HOME_TIMEOUT_S = 60.0
JOG_POSITION_PATTERN = re.compile(r"[-+]?\d*\.?\d+(?:[Ee][-+]?\d+)?")


class SerialCommError(RuntimeError):
    """The serial port itself failed (raised by _write/_query on a real
    serial.SerialException), as opposed to a transient bad/missing reply
    from the controller. Callers that retry on a generic RuntimeError
    (expecting the latter) must let this one propagate instead -- retrying
    against a dead port for a whole deadline just delays and mislabels the
    eventual failure as an unrelated timeout."""

# Autofocus: reuses focus_autocal.scan_focus_z, driving Z through JOG.move
# in-process (no HTTP round trip, unlike the standalone run_*.py scripts
# this was ported from). First scan of a session sweeps wide to find the
# surface; every scan after that -- including active-mode re-triggers after
# an X/Y move -- stays narrow around wherever the stage already sits, since
# a scan always ends by moving to its own peak.
# Wide is direction="down" only (0 .. -FOCUS_WIDE_RANGE_MM) -- the focus
# surface on this rig is always below the starting Z, so a symmetric +-
# sweep burned half its travel (and half the JOG Z-safety window) going the
# wrong way and could trip "outside Z safety range" before ever reaching
# the real surface.
FOCUS_WIDE_RANGE_MM = 2.0
FOCUS_WIDE_STEP_MM = 0.01
FOCUS_NARROW_RANGE_MM = 1.0
FOCUS_NARROW_STEP_MM = 0.01
FOCUS_Z_SPEED_MM_S = 0.3
# Camera timing: a fixed post-move dwell was proving too short/inconsistent
# (the background capture loop runs on its own ~15fps cadence, and a
# slow-auto-exposure frame's integration window can straddle a Z move) --
# see CameraController.wait_for_fresh(). FOCUS_MECH_SETTLE_S is only for
# physical vibration damping; the camera timing is covered by waiting for a
# frame timestamped after (move-complete + FOCUS_EXPOSURE_MARGIN_S).
FOCUS_MECH_SETTLE_S = 0.02
FOCUS_EXPOSURE_MARGIN_S = 0.05
FOCUS_FRAME_WAIT_TIMEOUT_S = 1.0
# A single camera frame's score is noisy -- a pixel flickering across
# CORE_MIN_GRAY between frames can swing the target blob's area (and
# whether a core is found at all) frame to frame, which showed up as the
# final scan graph having spiky/jumpy points. Averaging a few consecutive
# frames per Z step smooths that out without adding a real settle delay
# (frames just keep arriving at the camera's own ~15fps while we read them).
#
# 2-sample MEAN (the original fix) was not enough: live scan logs show the
# core-pairing dropping out to a hard score=0.0 on plenty of individual
# frames (not just a small wobble), and mean-of-2 lets a single 0.0 drag a
# real reading down by half or wipe it out entirely if both samples happen
# to land on a dropout. MEDIAN of an odd count of samples instead ignores
# up to (N-1)/2 dropped-out frames per step as long as the majority still
# see the spot -- verified against this rig's own captured scan data.
FOCUS_BRIGHTNESS_SAMPLES = 5
FOCUS_XY_DEBOUNCE_S = 0.6

# Trend prediction: fit a plane (z = a*x + b*y + c) through recent scan
# results and use it to pre-position Z *concurrently* with a deliberate
# goto() reposition (both axes get their PA command in the same locked
# block, so they physically move at the same time -- see goto()). This
# does NOT replace the narrow verification scan that still runs after the
# move settles: the settle dwell in each scan step is real camera-exposure
# time, not travel time, so prediction can't shrink it away without giving
# up the camera-confirmed guarantee. What it removes is the "start from
# wherever Z happened to be" cold start before that scan.
FOCUS_PLANE_MIN_SAMPLES = 3
FOCUS_PLANE_MAX_SAMPLES = 10
FOCUS_PREDICT_MAX_DELTA_MM = 0.1  # cap so a bad/ill-conditioned fit can't fling Z far on one move
FOCUS_LOG_PATH = ROOT / "focus_scan_log.csv"
# Separate files, not more columns on FOCUS_LOG_PATH: that CSV's header is
# only ever written once (on first creation) and every row since has relied
# on that fixed 9-column shape -- appending wider rows to it would misalign
# every existing reader (read_focus_log's DictReader included) against the
# old header. New data gets its own file instead.
FOCUS_QUALITY_LOG_PATH = ROOT / "focus_scan_quality_log.csv"
CAMERA_FREEZE_LOG_PATH = ROOT / "camera_freeze_log.csv"
SERIAL_RETRY_LOG_PATH = ROOT / "serial_retry_log.csv"
FOCUS_PHOTO_DIR = ROOT / "focus_photos"
FOCUS_PHOTO_LOG_PATH = ROOT / "focus_photo_log.csv"
FOCUS_PHOTO_WAIT_TIMEOUT_S = 2.0


def _append_csv_row(path: Path, header: list[str], row: list) -> None:
    """Shared best-effort CSV append: write `header` only if the file is
    new, then append `row`. Logging is diagnostic, never load-bearing --
    a disk hiccup here must not break whatever real operation triggered it."""
    try:
        is_new = not path.exists()
        with path.open("a", newline="", encoding="utf-8") as handle:
            writer = csv.writer(handle)
            if is_new:
                writer.writerow(header)
            writer.writerow(row)
    except OSError:
        pass


def _scan_quality_metrics(samples: list[tuple[float, float]]) -> dict:
    """Zero-dropout rate and curve roughness for one scan's (z, score)
    samples -- the same two numbers that took a one-off analysis script to
    compute during the 2026-09-09 focus-jaggedness investigation. Computed
    for every scan going forward instead of by hand after the fact."""
    values = [v for _, v in samples]
    n = len(values)
    if n == 0:
        return {"n": 0, "zeroCount": 0, "zeroPct": 0.0, "roughness": 0.0}
    zero_count = sum(1 for v in values if v == 0.0)
    peak = max(values) or 1.0
    total_variation = sum(abs(values[i + 1] - values[i]) for i in range(n - 1))
    return {
        "n": n,
        "zeroCount": zero_count,
        "zeroPct": round(100.0 * zero_count / n, 2),
        "roughness": round(total_variation / peak, 3),
    }


class JogController:
    """Manual jog interface for the ESP300 stage controller over serial.

    Each /api/jog/move call executes one discrete relative move, bounded by
    the usable glass circle (X/Y) and a fixed safety window (Z). The client
    issues repeated calls while a jog control is held.
    """

    def __init__(self) -> None:
        self._lock = threading.Lock()
        self.ser: serial.Serial | None = None
        self.dry_run = True
        self.connected = False
        self.port = ""
        self.baudrate = JOG_DEFAULT_BAUDRATE
        self.position = {"x": 12.5, "y": 12.5, "z": 0.0}
        self.raw_position = dict(self.position)
        self.local_offset = {"x": 0.0, "y": 0.0, "z": 0.0}
        self.home_ref = dict(self.position)
        # Raw (machine) Z at the last calibration point (connect/home/set
        # local home), used to bound live focus-trim jogging. focus_trim_mm
        # is the cumulative Z nudge applied via jog since that calibration;
        # it is folded into local_offset["z"] so every already-planned
        # focus/defocus target picks it up automatically (see move()).
        self.z_home_raw = 0.0
        self.focus_trim_mm = 0.0
        self.limit_center = (12.5, 12.5)
        self.limit_radius = 12.5
        self.z_range = JOG_Z_RANGE_MM
        self._poll_generation = 0
        self._run_thread: threading.Thread | None = None
        self._run_stop = threading.Event()
        self._run_state = {"running": False, "index": 0, "total": 0, "error": None, "done": False}

    def _write(self, cmd: str) -> None:
        if self.dry_run or self.ser is None:
            return
        try:
            self.ser.write((cmd + "\r\n").encode("ascii"))
        except serial.SerialException as exc:
            raise SerialCommError(f"Serial write failed for {cmd!r}: {exc}") from exc

    def _query(self, cmd: str) -> str:
        if self.dry_run or self.ser is None:
            return ""
        try:
            self.ser.reset_input_buffer()
            self.ser.write((cmd + "\r\n").encode("ascii"))
            # Poll without a fixed pre-delay, but require a line terminator
            # (\r or \n) before treating the reply as complete. A reply spanning
            # multiple USB-serial read chunks can otherwise be read as complete
            # after only a partial chunk, leaving trailing bytes in the buffer
            # that corrupt the next query's response.
            response = b""
            deadline = time.monotonic() + 0.3
            while time.monotonic() < deadline:
                if self.ser.in_waiting > 0:
                    response += self.ser.read(self.ser.in_waiting)
                    if b"\r" in response or b"\n" in response:
                        time.sleep(0.002)
                        if self.ser.in_waiting > 0:
                            response += self.ser.read(self.ser.in_waiting)
                        break
                else:
                    time.sleep(0.003)
        except serial.SerialException as exc:
            raise SerialCommError(f"Serial I/O failed for {cmd!r}: {exc}") from exc
        return response.decode("ascii", errors="ignore").strip()

    def _read_axis_position(self, axis: int) -> float:
        # A real serial.SerialException used to propagate straight out of
        # here on the very first occurrence, and every caller treated that
        # as "the port died" -- torn down the whole connection (see
        # SerialCommError handling in _poll_loop / _run_worker). But a lone
        # transient I/O hiccup on a still-good, still-open handle (one
        # dropped/garbled USB-serial read among the thousands a long "run on
        # machine" job generates) looks identical to a truly severed port at
        # that first exception. Folding SerialCommError into the SAME retry
        # budget as a bad/garbled reply -- instead of only retrying parse
        # mismatches -- means one bad round-trip no longer nukes an
        # otherwise-healthy connection mid-run; only a run of JOG_TP_RETRIES
        # consecutive real failures (parse or I/O) still gives up and
        # surfaces the error, which is what an actually-dead port looks like.
        last = ""
        last_comm_error: SerialCommError | None = None
        comm_error_attempts = 0
        for attempt in range(JOG_TP_RETRIES):
            try:
                last = self._query(f"{axis}TP")
                last_comm_error = None
            except SerialCommError as exc:
                last_comm_error = exc
                comm_error_attempts += 1
            else:
                match = JOG_POSITION_PATTERN.search(last)
                # Discard out-of-range values (parsing/framing artifacts) rather
                # than accepting them; the configured travel range is well
                # under 200 mm on every axis.
                if match and abs(float(match.group())) <= 250.0:
                    if comm_error_attempts:
                        # Recovered within the retry budget -- log it so a
                        # pattern of frequent transient hiccups is visible in
                        # data instead of only ever showing up as "it just
                        # disconnected sometimes" with nothing to point at.
                        _append_csv_row(
                            SERIAL_RETRY_LOG_PATH,
                            ["timestamp_utc", "axis", "comm_error_attempts", "outcome"],
                            [datetime.now(timezone.utc).isoformat(timespec="seconds"), axis, comm_error_attempts, "recovered"],
                        )
                    return float(match.group())
            if attempt < JOG_TP_RETRIES - 1:
                time.sleep(JOG_TP_RETRY_DELAY)
        if last_comm_error is not None:
            _append_csv_row(
                SERIAL_RETRY_LOG_PATH,
                ["timestamp_utc", "axis", "comm_error_attempts", "outcome"],
                [datetime.now(timezone.utc).isoformat(timespec="seconds"), axis, comm_error_attempts, "failed"],
            )
            raise last_comm_error
        raise RuntimeError(f"Axis {axis} position read failed; last reply={last!r}")

    def _raw_of(self, name: str, local_value: float) -> float:
        """Local (reported/design) coordinate -> true machine coordinate."""
        return local_value + self.local_offset[name]

    def _local_of(self, name: str, raw_value: float) -> float:
        """True machine coordinate -> local (reported/design) coordinate."""
        return raw_value - self.local_offset[name]

    def _refresh_limits(self) -> None:
        session = next(iter(SESSIONS.values()), None) if SESSIONS else None
        metadata = session["metadata"] if session else default_glass_metadata()
        center = metadata.get("usable_center_xy_mm") or [12.5, 12.5]
        diameter = float(metadata.get("usable_diameter_mm", 25.0))
        self.limit_center = (float(center[0]), float(center[1]))
        self.limit_radius = max(diameter / 2.0, 0.1)

    def _status_locked(self) -> dict:
        return {
            "connected": self.connected,
            "dryRun": self.dry_run,
            "port": self.port,
            "baudrate": self.baudrate,
            "position": dict(self.position),
            "focusTrimMm": round(self.focus_trim_mm, 6),
            "limit": {
                "centerX": self.limit_center[0],
                "centerY": self.limit_center[1],
                "radiusMm": self.limit_radius,
                "zRangeMm": self.z_range,
            },
        }

    def _disconnect_locked(self) -> None:
        self._poll_generation += 1
        if self.ser is not None:
            try:
                for axis in JOG_AXES.values():
                    self._write(f"{axis}MF")
            except Exception:
                pass
            try:
                self.ser.close()
            except Exception:
                pass
        self.ser = None
        self.connected = False

    def _poll_loop(self, generation: int) -> None:
        """Background thread: refresh self.position from TP reads so status
        queries reflect current motion without blocking on move(). Exits
        when disconnect/estop increments the generation counter.

        Skips its own querying while a plan run (_run_worker) is active:
        that worker already TP-polls the exact axes it's moving to confirm
        arrival, so running both at once was hitting the ESP300 with two
        independent, uncoordinated streams of TP queries for the whole
        length of every "run on machine" job -- roughly doubling serial
        traffic for no benefit (self.position gets updated by _run_worker's
        own polling either way) and doubling the exposure window for
        whatever transient causes the occasional mid-run disconnect."""
        while True:
            for name, axis in JOG_AXES.items():
                with self._lock:
                    if self._poll_generation != generation or not self.connected or self.dry_run or self.ser is None:
                        return
                    if self._run_state["running"]:
                        continue
                    try:
                        raw = self._read_axis_position(axis)
                        self.raw_position[name] = raw
                        self.position[name] = self._local_of(name, raw)
                    except SerialCommError:
                        # The port itself died -- retrying every 5ms forever
                        # would otherwise spin silently with connected still
                        # showing True. Tear down the connection so status()
                        # reflects reality and a run in progress sees it.
                        self._disconnect_locked()
                        return
                    except RuntimeError:
                        pass
                time.sleep(0.005)
            time.sleep(0.02)

    def status(self) -> dict:
        with self._lock:
            return self._status_locked()

    def connect(
        self,
        port: str,
        baudrate: int,
        dry_run: bool,
        range_xy_mm: float | None = None,
        range_z_mm: float | None = None,
    ) -> dict:
        with self._lock:
            self._disconnect_locked()
            self.dry_run = bool(dry_run)
            self.port = str(port or "COM5")
            self.baudrate = int(baudrate or JOG_DEFAULT_BAUDRATE)
            self._refresh_limits()
            # An explicit range from the client overrides the traced-session
            # glass circle, for jog operations unrelated to the loaded job.
            if range_xy_mm:
                self.limit_radius = max(0.1, float(range_xy_mm))
            self.z_range = max(0.1, float(range_z_mm)) if range_z_mm else JOG_Z_RANGE_MM
            # Fresh connection: local frame starts equal to the real machine
            # frame (offset 0) until set_local_home() is explicitly called.
            # True machine home itself is never touched here or anywhere else.
            self.local_offset = {"x": 0.0, "y": 0.0, "z": 0.0}
            if not self.dry_run:
                self.ser = serial.Serial(
                    port=self.port,
                    baudrate=self.baudrate,
                    bytesize=serial.EIGHTBITS,
                    parity=serial.PARITY_NONE,
                    stopbits=serial.STOPBITS_ONE,
                    timeout=2,
                    rtscts=True,
                )
                for axis in JOG_AXES.values():
                    self._write(f"{axis}MO")
                    time.sleep(JOG_MOTOR_SETTLE_S)
                for name, axis in JOG_AXES.items():
                    raw = self._read_axis_position(axis)
                    self.raw_position[name] = raw
                    self.position[name] = raw
            else:
                self.position = {"x": self.limit_center[0], "y": self.limit_center[1], "z": 0.0}
                self.raw_position = dict(self.position)
            # Recenter the soft limit on the current stage position, in case
            # it does not match the last traced session's glass center.
            self.limit_center = (self.position["x"], self.position["y"])
            self.home_ref = dict(self.position)
            self.z_home_raw = self.raw_position["z"]
            self.focus_trim_mm = 0.0
            FOCUS.reset_plane()
            self.connected = True
            self._poll_generation += 1
            generation = self._poll_generation
            if not self.dry_run:
                threading.Thread(target=self._poll_loop, args=(generation,), daemon=True).start()
            return self._status_locked()

    def disconnect(self) -> dict:
        with self._lock:
            self._disconnect_locked()
            return self._status_locked()

    def move(self, axis_name: str, delta_mm: float, speed_mm_s: float) -> dict:
        if axis_name not in JOG_AXES:
            raise ValueError(f"Unknown jog axis {axis_name!r}.")
        with self._lock:
            if not self.connected:
                raise RuntimeError("Jog not connected. Connect first.")
            axis = JOG_AXES[axis_name]
            delta = max(-JOG_STEP_MAX_MM, min(JOG_STEP_MAX_MM, float(delta_mm)))
            speed = max(0.01, min(JOG_SPEED_MAX_MM_S, float(speed_mm_s)))
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

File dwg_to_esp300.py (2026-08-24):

from __future__ import annotations

import argparse
import fnmatch
import json
import math
import re
import shutil
import sys
import tempfile
from dataclasses import dataclass
from pathlib import Path
from typing import Iterable, Sequence

import ezdxf
from ezdxf import bbox, disassemble, path
from ezdxf.addons import odafc


Point = tuple[float, float]


DEFAULT_FEED_RATE_MM_S = 0.4
DEFAULT_TRAVEL_RATE_MM_S = 1.0
DEFAULT_Z_DEFOCUS_MM = 1.0
DEFAULT_Z_SPEED_MM_S = 0.3
DEFAULT_COMMAND_SETTLE_S = 0.05
DEFAULT_POSITION_TOLERANCE_MM = 0.003


INSUNITS_TO_MM = {
    1: 25.4,  # inches
    2: 304.8,  # feet
    4: 1.0,  # millimeters
    5: 10.0,  # centimeters
    6: 1000.0,  # meters
}


@dataclass
class LaserPath:
    points: list[Point]
    layer: str
    entity_type: str
    closed: bool = False

    @property
    def start(self) -> Point:
        return self.points[0]

    @property
    def end(self) -> Point:
        return self.points[-1]

    @property
    def length(self) -> float:
        return polyline_length(self.points)


@dataclass
class DrawingData:
    paths: list[LaserPath]
    source_path: Path
    dxf_path: Path
    unit_scale: float
    raw_bbox: tuple[Point, Point]
    machine_bbox: tuple[Point, Point]
    skipped: dict[str, int]


def distance(a: Point, b: Point) -> float:
    return math.hypot(a[0] - b[0], a[1] - b[1])


def polyline_length(points: Sequence[Point]) -> float:
    return sum(distance(a, b) for a, b in zip(points, points[1:]))


def dedupe_points(points: Iterable[Point], tolerance: float = 1e-9) -> list[Point]:
    clean: list[Point] = []
    for point in points:
        if not clean or distance(clean[-1], point) > tolerance:
            clean.append(point)
    return clean


def split_long_segments(points: Sequence[Point], max_segment: float) -> list[Point]:
    if max_segment <= 0 or len(points) < 2:
        return list(points)

    result = [points[0]]
    for start, end in zip(points, points[1:]):
        segment_length = distance(start, end)
        if segment_length <= max_segment:
            result.append(end)
            continue

        steps = max(1, math.ceil(segment_length / max_segment))
        for step in range(1, steps + 1):
            t = step / steps
            result.append(
                (
                    start[0] + (end[0] - start[0]) * t,
                    start[1] + (end[1] - start[1]) * t,
                )
            )
    return result


def close_if_needed(points: list[Point], closed: bool, tolerance: float = 1e-7) -> list[Point]:
    if closed and len(points) > 2 and distance(points[0], points[-1]) > tolerance:
        points = [*points, points[0]]
    return points


def decode_dxf_unicode_escapes(text: str) -> str:
    return re.sub(r"\\U\+([0-9A-Fa-f]{4})", lambda match: chr(int(match.group(1), 16)), text)


def matches_layer(layer: str, include: Sequence[str], exclude: Sequence[str]) -> bool:
    candidates = {layer, decode_dxf_unicode_escapes(layer)}
    if include and not any(fnmatch.fnmatchcase(candidate, pattern) for candidate in candidates for pattern in include):
        return False
    if exclude and any(fnmatch.fnmatchcase(candidate, pattern) for candidate in candidates for pattern in exclude):
        return False
    return True


def layer_name(laser_path: LaserPath) -> str:
    return decode_dxf_unicode_escapes(laser_path.layer)


ANNOTATION_LAYER_KEYWORDS = (
    "annotation",
    "anno",
    "dim",
    "dimension",
    "text",
    "eval",
    "evaluation",
    "watermark",
    "title",
    "note",
    "center",
    "hidden",
    "construction",
    "치수",
    "문자",
    "주석",
    "평가",
)


def looks_like_annotation_layer(name: str) -> bool:
    lowered = name.lower()
    return any(keyword in lowered for keyword in ANNOTATION_LAYER_KEYWORDS)


def looks_like_global_diagonal(laser_path: LaserPath, drawing_bbox: tuple[Point, Point]) -> bool:
    (min_x, min_y), (max_x, max_y) = drawing_bbox
    width = max(max_x - min_x, 1e-9)
    height = max(max_y - min_y, 1e-9)
    xs = [point[0] for point in laser_path.points]
    ys = [point[1] for point in laser_path.points]
    path_width = max(xs) - min(xs)
    path_height = max(ys) - min(ys)
    return len(laser_path.points) == 2 and path_width >= width * 0.9 and path_height >= height * 0.9


def select_design_paths(paths: Sequence[LaserPath], skipped: dict[str, int]) -> list[LaserPath]:
    layers = {layer_name(laser_path) for laser_path in paths}
    if not paths:
        return []

    drawing_bbox = raw_bbox(paths)

    def without_global_diagonals(candidates: Sequence[LaserPath]) -> list[LaserPath]:
        selected: list[LaserPath] = []
        for laser_path in candidates:
            if looks_like_global_diagonal(laser_path, drawing_bbox):
                skipped["auto_trace_diagonal"] = skipped.get("auto_trace_diagonal", 0) + 1
                continue
            selected.append(laser_path)
        return selected

    nonzero_paths = [laser_path for laser_path in paths if layer_name(laser_path) not in {"0", "Defpoints"}]
    design_named_paths = [
        laser_path
        for laser_path in nonzero_paths
        if not looks_like_annotation_layer(layer_name(laser_path))
    ]

    if design_named_paths:
        skipped["auto_trace_layer_0"] = len(paths) - len(nonzero_paths)
        skipped["auto_trace_annotation_layer"] = len(nonzero_paths) - len(design_named_paths)
        return without_global_diagonals(design_named_paths)

    if nonzero_paths:
        skipped["auto_trace_layer_0"] = len(paths) - len(nonzero_paths)
        return without_global_diagonals(nonzero_paths)

    selected = []
    for laser_path in paths:
        if looks_like_global_diagonal(laser_path, drawing_bbox):
            skipped["auto_trace_diagonal"] = skipped.get("auto_trace_diagonal", 0) + 1
            continue
        selected.append(laser_path)

    skipped["auto_trace_layers"] = len(layers)
    return selected


def convert_dwg_with_aspose(source: Path, dxf_path: Path) -> None:
    try:
        import aspose.cad as cad
    except Exception as exc:  # pragma: no cover - depends on optional package
        raise RuntimeError("aspose-cad is not installed") from exc

    with tempfile.TemporaryDirectory(prefix="dwg_to_esp300_") as temp_dir:
        temp_source = Path(temp_dir) / source.name
        shutil.copy2(source, temp_source)
        with cad.Image.load(str(temp_source)) as image:
            options = cad.imageoptions.DxfOptions()
            image.save(str(dxf_path), options)
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

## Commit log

2026-08-24 Initial commit: DWG to ESP300 lab code package
    [adjust25design_162728ca961a_esp300.converted.dxf, adjust25design_16fdf3114810_esp300.converted.dxf, adjust25design_2ced8849e027_esp300.converted.dxf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]
2026-08-24 Fix camera capture loop spamming grabFrame warnings; remove junk log/cache files
    [visualizer_server.py]
2026-08-30 Add multi-method Z-autofocus: blob/reflection-filtered scoring, XY survey + plane-fit predictive Z, auto-rescan watch loop
    - focus_autocal.py: adaptive coarse/fine scan refinements
    - visualizer_server.py: wide/narrow scan stages, plane-sample accumulation,
    predict_z() from recent scan trend, XY-stop auto-rescan watch loop,
    focus_scan_log.csv per-scan logging
    - app.js/index.html/styles.css: UI for survey + live focus status
    - new data/output: focus_scan_log.csv (+meanmetric archive), z_micron_scan
    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
    [adjust25design_095c64d77f16_esp300.converted.dxf, adjust25design_09d05904adc8_esp300.converted.dxf, adjust25design_28c4ba191b08_esp300.converted.dxf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]
2026-09-10 fix(focus): stop scan jaggedness, add safety watchdogs
    Root cause: locate_bright_regions() scored 0.0 whenever no red+core
    pair was found (34% of samples on this rig) instead of degrading
    smoothly. median-of-5 + red-glow fallback score fixes it (verified
    0% dropouts on real hardware).
    Also, found live during today's session:
    - camera driver can freeze on a duplicate frame forever (ok=True,
    content unchanged) -- now detected and disconnected like a real
    dropped connection.
    - run-on-machine dropped mid-run from a single transient serial
    hiccup, and from redundant polling doubling serial traffic during
    a run -- both fixed.
    - launch_dwg_to_esp300.ps1 was hardcoded to port 8766, a reserv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
    [adjust25design_046a65ac8106_esp300.converted.dxf, adjust25design_3bd0403941c3_esp300.converted.dxf, adjust25design_4a1f72b4e963_esp300.converted.dxf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]
2026-09-10 docs: add end-user guide (Korean + English)
    Apple/Notion-style illustrated user guide, built from real screenshots
    of the running app with numbered callouts (not invented screens) --
    covers loading a drawing, camera + autofocus, jogging, running a job,
    Shapes/Paths tabs, settings, and troubleshooting in plain language.
    Companion to MANUAL.pdf/UI_MAP.pdf, which stay developer-facing.
2026-09-11 fix(focus): prior_xy distance/area gate + velocity prediction, ceramic-center finding, run resume
    - locate_bright_regions(): add MAX_PRIOR_JUMP_PX distance gate and
    MIN_CANDIDATE_AREA_PX noise-area gate to the prior_xy nearest-match, so a
    stray reflection farther than plausible or too small can't hijack the
    tracked target (root cause of the residual scan-time-variance spikes).
    - Extract _predict_xy()/_update_velocity_xy(): track prior_xy's own
    frame-to-frame velocity (smoothed) and anchor the gate on prior+velocity
    instead of a static prior, so a straight-line stage move is predicted
    ahead of time instead of only reacted to a frame late.
    - Run-on-machine: add /api/run/start resum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
    [focus_scan_log.csv]
